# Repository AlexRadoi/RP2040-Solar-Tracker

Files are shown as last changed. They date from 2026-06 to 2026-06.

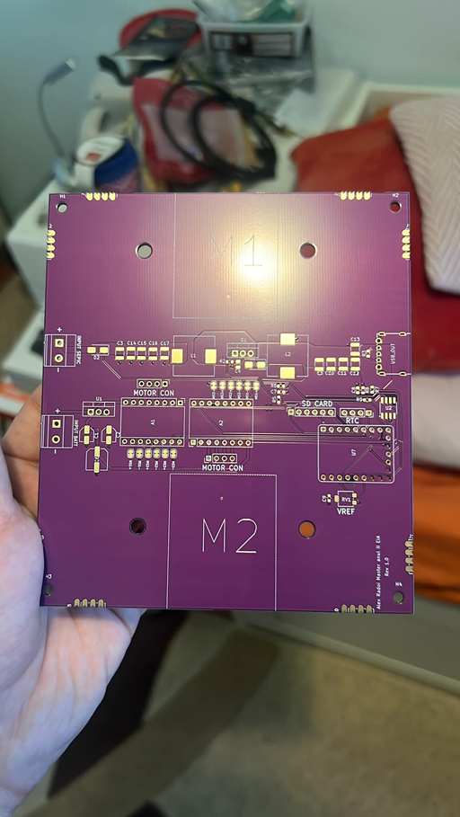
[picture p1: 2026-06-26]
image.png

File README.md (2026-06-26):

# RP2040-Solar-Tracker
RP2040 Single axis solar tracker
This project was my final masters project and involves the development of a simple single axis solar tracker based on an open loop astronomical algorithm and providing output power through a SEPIC converter and logging all data by creating an .cvs file on an SD card.

The final prototype :
WhatsApp Image 2026-06-17 at 10 14 57
WhatsApp Image 2026-06-17 at 10 14 57 (1)

Output from the RP2040 microcontroller:



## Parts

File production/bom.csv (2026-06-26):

Designator | Footprint | Quantity | Value | LCSC Part #
A1, A2 | Pololu_Breakout-16_15.2x20.3mm | 2 | Pololu_Breakout_A4988
C1, C2 | C_Elec_4x5.4 | 2 | 10u
C10, C11, C12, C13, C5 | 1210 | 5 | 22u
C14, C15, C16, C17, C3 | 1210 | 5 | 22uF
C4 | 0805 | 1 | 1uF
C6 | C_Elec_6.3x5.4 | 1 | 100uF
C7, C8, C9 | 0603 | 3 | 100n
D1, D2 | D_SMA | 2 | SS34
INPUT BATT | TerminalBlock_Phoenix_MKDS-1,5-2-5.08_1x02_P5.08mm_Horizontal | 1 | BATT
J | TerminalBlock_Phoenix_MKDS-1,5-2-5.08_1x02_P5.08mm_Horizontal | 1 | SOLAR_PANEL
J10, J11, J12, J13, J14, J15, J8, J9 | Castelations_1x4 | 8 | Conn_01x04_Pin
J3 | PinHeader_1x04_P2.54mm_Vertical | 1 | MOT_1
J4 | PinHeader_1x04_P2.54mm_Vertical | 1 | MOT_2
J5 | PinSocket_1x04_P2.54mm_Vertical | 1 | RTC_MODULE
J6 | PinSocket_1x06_P2.54mm_Vertical | 1 | SD_Card_Module
L1, L2 | L_Changjiang_FXL1370 | 2 | 100uH
Q1 | TO-220-3_Vertical | 1 | IRL540
R2 | 0603 | 1 | 100k
R3 | 0603 | 1 | 0R
R5 | 0603 | 1 | 30k
R6, R7, R8 | 0603 | 3 | 10k
R9 | 0603 | 1 | 22R
RV1 | Potentiometer_Bourns_3314G_Vertical | 1 | 10k
U1 | TO-220-3_Vertical | 1 | L7805
U2 | SOIC-8_3.9x4.9mm_P1.27mm | 1 | TC4427xOA
U7 | MODULE_RP2040-ZERO | 1 | RP2040-ZERO
USB_OUT | USB_XDBF | 1 | USB_A

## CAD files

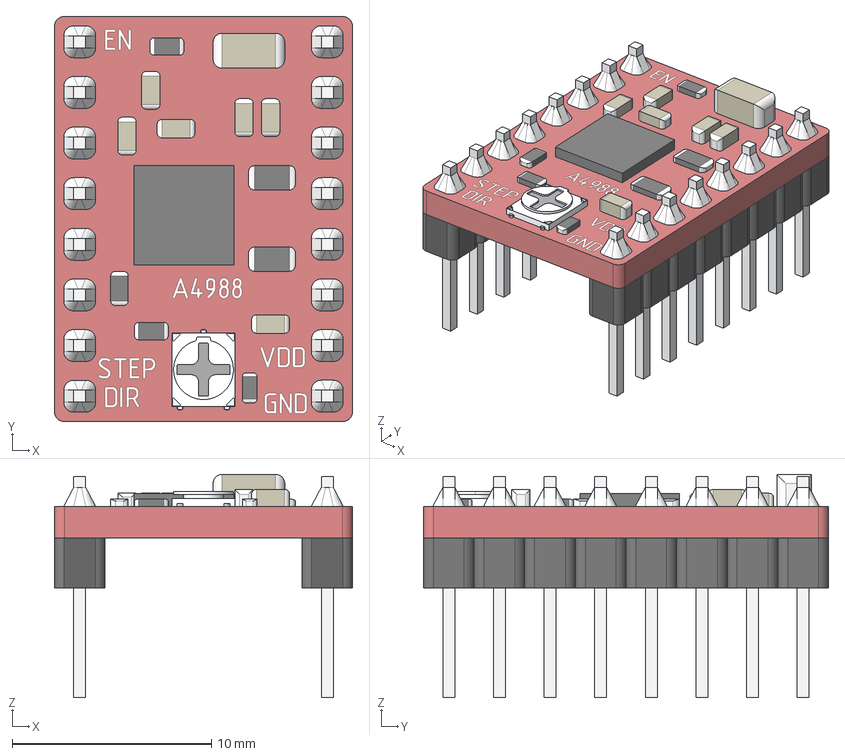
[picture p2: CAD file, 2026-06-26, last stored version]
3D_Models_PCB/A4988-Stepper-Driver-WithPins.stp
15.0 x 20.3 x 11.2 mm

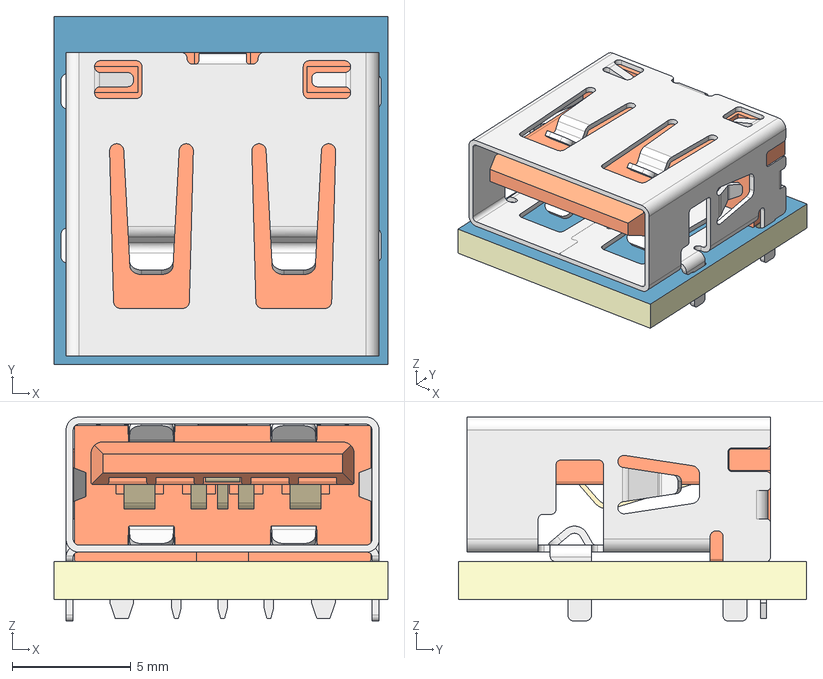
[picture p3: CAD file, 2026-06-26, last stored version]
3D_Models_PCB/3D_PCB1_2026-04-07.step
14.1 x 14.7 x 8.60 mm
Board~0Qz9
TopCopper~0Qz9
BottomCopper~0Qz9
TopFpcStiffener~0Qz9
BottomFpcStiffener~0Qz9
USB-TH_XDBF-0050-01~USB-TH_XDBF-0050-01~0Qz9

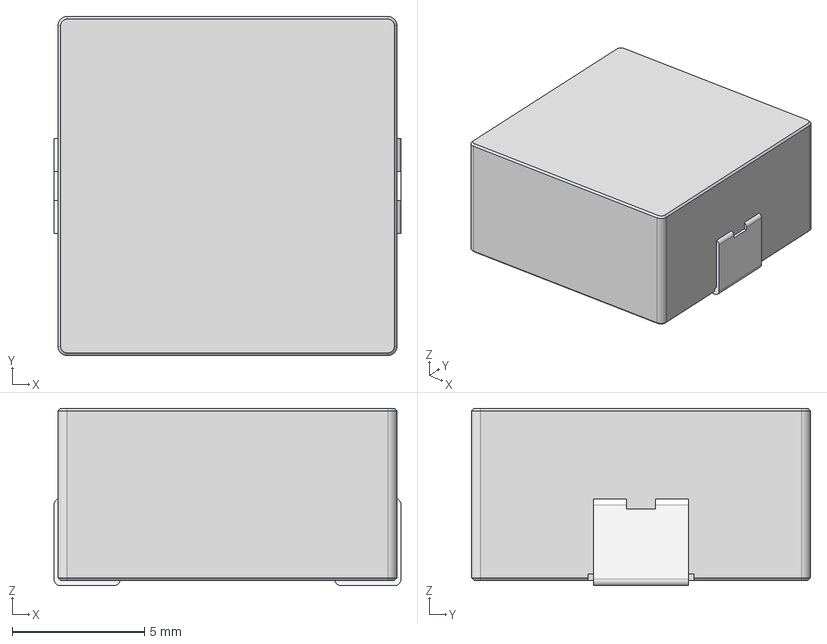
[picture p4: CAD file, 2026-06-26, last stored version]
3D_Models_PCB/CIP1265.step
13.1 x 12.8 x 6.70 mm
Leads

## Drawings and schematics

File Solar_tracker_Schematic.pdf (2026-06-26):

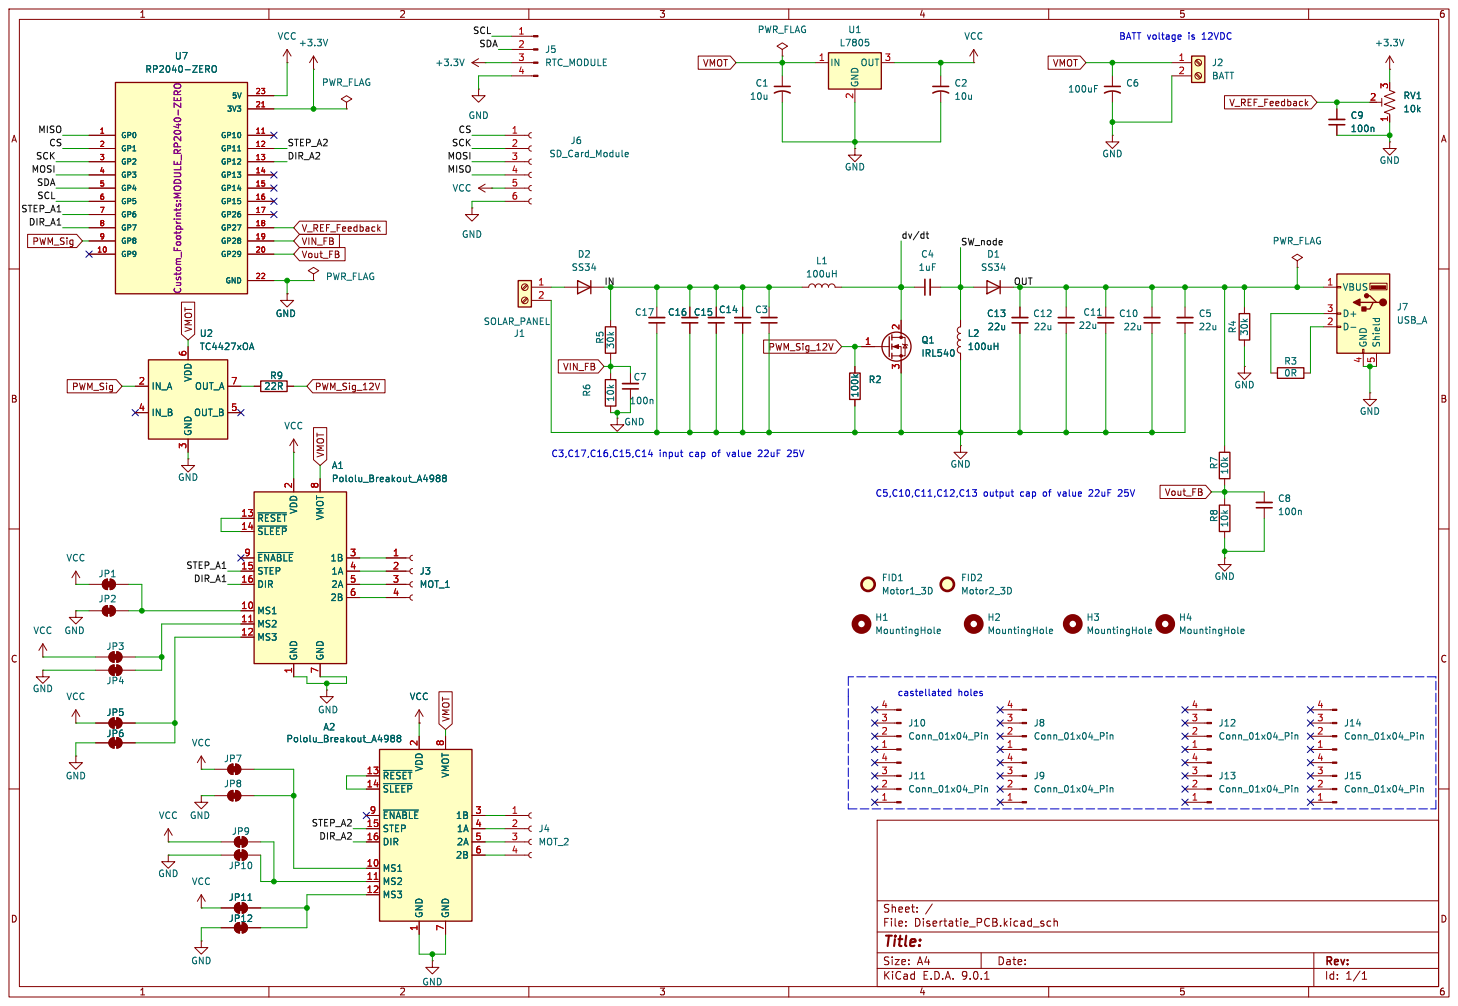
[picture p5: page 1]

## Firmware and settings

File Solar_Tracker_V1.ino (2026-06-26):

#include <Arduino.h>
#include <SPI.h>
#include <SD.h>
#include <Wire.h>
#include "RTClib.h"
#include <SolarPosition.h>
#include <AccelStepper.h>

// --- Hardware Pin Allocations ---
const int chipSelect = 1;      // MicroSD Card CS pin
const int pinPWM = 8;          // PWM output for SEPIC MOSFET gate driver (GP8)
const int pinPot = 29;         // ADC input for Target Voltage reference potentiometer
const int pinFeedback = 28;    // ADC input for SEPIC Output Voltage feedback
const int pinVin = 27;         // ADC input for Solar Panel Input Voltage monitoring

// Stepper Motor Driver Interfaces (A4988)
const int step1 = 6;  const int dir1 = 7;   // Primary Axis Stepper (Motor 1)
const int step2 = 11; const int dir2 = 12;  // Secondary Axis Mirror Stepper (Motor 2)

// --- Physical and Geometric Constants ---
const float LATITUDE = 44.4268;         // Bucharest coordinates
const float LONGITUDE = 26.1025;
const float stepsPerDegree = 8.88888;  // Mechanical resolution (Motor steps per kinematic degree)
const float referenceVoltage = 3.3;    // RP2040 ADC reference voltage (VREF)

// Hardware travel boundaries (-45° East to +45° West)
const long stepsMin = (long)(-45.0 * stepsPerDegree); // East Park Position (~ -400 steps)
const long stepsMax = (long)(45.0 * stepsPerDegree);  // West Park Position (~ +400 steps)

// --- Shared Inter-Core Volatile Variables (IPC) ---
volatile long globalTargetSteps = 0;   // Calculated target position from Core 1 to Core 0
volatile float sharedInV = 0;          // Solar voltage acquired by Core 0, logged by Core 1
volatile float sharedOutV = 0;         // SEPIC voltage acquired by Core 0, logged by Core 1
volatile float sharedAzimuth = 0;      // Astronomical Azimuth for logging and telemetry
volatile float sharedElevation = 0;     // Astronomical Elevation for logging and telemetry
volatile float pwmVal = 0;             // Current Duty Cycle value for the SEPIC loop

// --- Chronological Tracking Profile Variables ---
int dynamicNoonMinute = 615;           // Fallback Solar Noon value (10:15 UTC in minutes)
int lastScanDay = -1;                  // Tracks calendar day changes to trigger the daily solar scan

// Object Instantiations
RTC_DS3231 rtc;
SolarPosition bucharestSolar(LATITUDE, LONGITUDE);
AccelStepper stepper1(AccelStepper::DRIVER, step1, dir1);
AccelStepper stepper2(AccelStepper::DRIVER, step2, dir2);

// Automatic Daylight Saving Time (DST) Logic for Romania
int getUtcOffset(DateTime dt) {
  int m = dt.month(); int d = dt.day(); int dow = dt.dayOfTheWeek();
  if (m < 3 || m > 10) return 2;  // Winter Time: UTC+2
  if (m > 3 && m < 10) return 3;  // Summer Time (DST): UTC+3
  if (m == 3) return (d - dow >= 25) ? 3 : 2;   // Last Sunday of March transition
  if (m == 10) return (d - dow >= 25) ? 2 : 3;  // Last Sunday of October transition
  return 2;
}

// ============================================================================
// CORE 0: REAL-TIME EXECUTION (SEPIC CONVERTER LOOP & STEPPER ACCELERATION)
// ============================================================================
void setup() {
  analogReadResolution(12);       // Configure ADC to 12-bit resolution (0 - 4095)
  pinMode(pinPWM, OUTPUT);
  analogWriteFreq(200000);        // 200kHz switching frequency for SEPIC inductor efficiency
  analogWriteRange(1000);         // 0 - 1000 dynamic range for fine duty cycle adjustments

  // Configure movement profiles for both stepper actuators (adjusted for high microstepping)
  stepper1.setMaxSpeed(4000);      
  stepper1.setAcceleration(1000);
  stepper2.setMaxSpeed(4000);
  stepper2.setAcceleration(1000);

  // Perform initial 360-degree rotation at boot
  long fullSweepSteps = (long)(360.0 * stepsPerDegree);
  //stepper1.move(fullSweepSteps);
  //stepper2.move(fullSweepSteps);
  
  // Block and execute the movement until both steppers finish their 360-degree rotation
  while (stepper1.distanceToGo() != 0 || stepper2.distanceToGo() != 0) {
    stepper1.run();
    stepper2.run();
  }
  
  // Reset current positions to 0 to establish the new origin point for tracking
  stepper1.setCurrentPosition(0);
  stepper2.setCurrentPosition(0);
}

void loop() {
  // 1. SEPIC PWM Feedback Loop (Priority 1 - Runs strictly every 5ms)
  static unsigned long lastSepicUpdate = 0;
  if (millis() - lastSepicUpdate >= 5) { 
    lastSepicUpdate = millis();
    int targetV = analogRead(pinPot);      // Desired output voltage reference
    int actualV = analogRead(pinFeedback); // Real-time feedback from output rail
    int inVRaw = analogRead(pinVin);       // Input voltage from solar panel
    
    // Safety check: shut down PWM if there is no input voltage
    // Prevents duty cycle from ramping to 100% and burning the converter
    if(actualV  > 3800){ 
        pwmVal = 0;
      }
    else if (inVRaw < 50) { // ~40mV threshold on the ADC pin
      pwmVal = 0;
    } else {
      // Incremental integral control action for voltage stabilization
      if (abs(targetV - actualV) > 5) {
        if (targetV > actualV) pwmVal += 1.0; 
        else pwmVal -= 1.0;
      }
    }
    pwmVal = constrain(pwmVal, 0, 1000);    // Safety clamp
    analogWrite(pinPWM, (int)pwmVal);
  }

  // 2. Stepper Motion Execution (Priority 2 - Non-blocking tracking update)
  stepper1.moveTo((long)(globalTargetSteps));
  stepper2.moveTo((long)(globalTargetSteps));
  stepper1.run();
  stepper2.run();

  // Detect state changes to print movement events
  static bool wasMoving = false;
  bool isMoving = (stepper1.distanceToGo() != 0 || stepper2.distanceToGo() != 0);
  if (isMoving != wasMoving) {
    if (isMoving) {
      Serial.println("\n>> ACTUATORS: Motion started towards target...");
    } else {
      Serial.println(">> ACTUATORS: Target position reached.\n");
    }
    wasMoving = isMoving;
  }
  

  // 3. Sensor Scaling (Convert raw ADC counts to physical voltages)
  sharedInV = (analogRead(pinVin) / 4095.0) * referenceVoltage;
  sharedOutV = (analogRead(pinFeedback) / 4095.0) * referenceVoltage;
}

// ============================================================================
// CORE 1: RESOURCE MANAGEMENT (ASTRONOMY, TIME MAPPING & DATA SD LOGGING)
// ============================================================================
void setup1() {
  Serial.begin(115200);
  delay(2000); // Guard window allowing Core 0 loops and power rails to stabilize
  
  Wire.setSDA(4); Wire.setSCL(5); Wire.begin(); // Map I2C lines for RTC communication
  
  // Explicit Hardware SPI0 Mapping for RP2040-Zero Form Factor
  SPI.setRX(0);   // MISO = GP0
  SPI.setTX(3);   // MOSI = GP3
  SPI.setSCK(2);  // SCK  = GP2
  
  if (!rtc.begin()) {
    Serial.println("Error: RTC hardware module not found!");
  } else {
    Serial.println("RTC module initialized successfully.");
    
    // Check if the RTC lost power and needs to be set, or force update it
    if (rtc.lostPower()) {
      Serial.println("RTC lost power, setting time to compile time!");
      // This sets the RTC to the date & time this sketch was compiled
      rtc.adjust(DateTime(F(__DATE__), F(__TIME__)));
    }
    // UNCOMMENT THE LINE BELOW TO FORCE UPDATE THE TIME ON EVERY REBOOT:
    // rtc.adjust(DateTime(F(__DATE__), F(__TIME__)));
  }
  
  // SD Card File System Initialization
  if (SD.begin(chipSelect)) {
    Serial.println("SD card initialization successful.");
    if (!SD.exists("log.csv")) {
      File f = SD.open("log.csv", FILE_WRITE);
      if (f) {
        // Updated structure containing full solar telemetry vectors
        f.println("Time,SolarIn,SepicOut,Azimuth,Elevation,Steps");
        f.close();
        Serial.println("Created log.csv file header.");
      }
    }
  } else {
    Serial.println("Critical Error: SD card initialization failed!");
  }
}

void loop1() {
  DateTime now = rtc.now(); // Poll current local time from the hardware clock

  // 1. DAILY SOLAR SCAN (Executes once per 24 hours at midnight)
  // Computes the exact UTC minute where the sun crosses true South (Azimuth = 180 degrees)
  if (now.day() != lastScanDay) {
    float minAzDiff = 360.0;
    int foundNoonMinute = 615; // Reset to default safe fallback

    // Virtual high-speed tracking loop covering 08:00 UTC (480m) to 14:00 UTC (840m)
    for (int minutes = 480; minutes <= 840; minutes++) {
      DateTime testTime(now.year(), now.month(), now.day(), 0, 0, 0);
      long testUnix = testTime.unixtime() + (minutes * 60);
      SolarPosition_t solTest = bucharestSolar.getSolarPosition(testUnix);
      
      float azDiff = abs(solTest.azimuth - 180.0);
      if (azDiff < minAzDiff) {
        minAzDiff = azDiff;
        foundNoonMinute = minutes; // Store computed astronomical solar noon minute
      }
    }
    dynamicNoonMinute = foundNoonMinute;
    lastScanDay = now.day();
    
    Serial.print("Daily profile updated. Dynamic Solar Noon calculated at UTC minute: ");
    Serial.println(dynamicNoonMinute);
  }

  // 2. REAL-TIME SOLAR DATA ACQUISITION
  // Translate local RTC time into absolute UTC minutes elapsed from midnight
  long utcUnix = now.unixtime() - (getUtcOffset(now) * 3600);
  SolarPosition_t currentSol = bucharestSolar.getSolarPosition(utcUnix);
  sharedAzimuth = currentSol.azimuth;
  sharedElevation = currentSol.elevation;

  // 3. ASTRONOMICAL MAPPING & NIGHTTIME REVERSAL LOGIC
  // The sun crosses True South at exactly 180.0 degrees Azimuth.
  // Hardware limits are -45° East (135° Azimuth) to +45° West (225° Azimuth).
  if (sharedElevation > 0) { 
    // Daytime Operation: Sun is above the horizon
    if (sharedAzimuth < 135.0) {
      // Early Morning: Sun is further East than the hardware limits. Park at East limit.
      globalTargetSteps = stepsMin;
    } 
    else if (sharedAzimuth > 225.0) {
      // Late Afternoon: Sun is further West than the hardware limits. Park at West limit.
      globalTargetSteps = stepsMax;
    }  
    else {
      // Active Tracking Window: Map astronomical Azimuth directly to physical microsteps.
      // This provides perfect non-linear tracking compensating for the sun's actual arc.
      globalTargetSteps = map(sharedAzimuth, 135.0, 225.0, stepsMin, stepsMax);
    }
  } else {
    // Night Routine / Reversal Phase: Sun is below the horizon
    // Automatically returns the array back to the maximum East position (-45°)
    // This pre-positions the mechanics safely for the next day's dawn cycle.
    globalTargetSteps = stepsMin; 
  }

  // 5. DATA LOGGING ROUTINE (SD Card Flash Write)
  File dataFile = SD.open("log.csv", FILE_WRITE);
  
  if (!dataFile) {
    // Automated hot-plugging recovery routine if SD card drops offline
    SD.begin(chipSelect);
    dataFile = SD.open("log.csv", FILE_WRITE);
  }
  
  if (dataFile) {
    char buf[] = "hh:mm:ss";
    dataFile.print(now.toString(buf)); dataFile.print(",");
    dataFile.print(sharedInV, 2); dataFile.print(",");
    dataFile.print(sharedOutV, 2); dataFile.print(",");
    dataFile.print(sharedAzimuth, 2); dataFile.print(",");     // Log absolute real-time Azimuth
    dataFile.print(sharedElevation, 2); dataFile.print(",");   // Log absolute real-time Elevation
    dataFile.println(globalTargetSteps);                      // Log actual ordered stepper position
    dataFile.close();
    Serial.println("Telemetry batch logged to SD card.");
  } else {
    Serial.println("Error: Failed to write data to log.csv");
  }

  // 6. SERIAL TELEMETRY MONITORING (For terminal interface during bench testing)
  Serial.println("\n=== DUAL-CORE SYSTEM TELEMETRY ===");
  char timeBuf[] = "YYYY-MM-DD hh:mm:ss";
  Serial.print("Local System Time: "); Serial.println(now.toString(timeBuf));
  Serial.print("Solar Array Voltage (PV In): "); Serial.print(sharedInV, 2); Serial.println(" V");
  Serial.print("SEPIC Rail Output (DC Out): "); Serial.print(sharedOutV, 2); Serial.println(" V");
  Serial.print("Astronomical Vector -> Azimuth: "); Serial.print(sharedAzimuth, 2);
  Serial.print(" deg | Elevation: "); Serial.print(sharedElevation, 2); Serial.println(" deg");
  Serial.print("Actuator Control   -> Target Steps: "); Serial.println(globalTargetSteps);
  Serial.println("==================================");

  delay(1000); // Fixed management loop interval (1-second updates)
}

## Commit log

2026-06-26 All the production files for the PCB
    [bom.csv, designators.csv, positions.csv]
2026-06-26 3d Models used for the PCB
    [3D_PCB1_2026-04-07.step, A4988-Stepper-Driver-WithPins.stp, CIP1265.step]
2026-06-26 Schematic diagram for the project
